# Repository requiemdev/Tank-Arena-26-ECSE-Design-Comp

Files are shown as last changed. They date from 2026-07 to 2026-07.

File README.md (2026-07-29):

# Tank Arena — Laser Tank Duels

**Winner of the Part III Engineering Excellence Award at the 2026 University of Auckland ECSE Design Competition.**



Tank Arena is a two-player tank duel game that combines custom 3D-printed tanks, ESP32 embedded firmware, electrical design, and a browser-based control experience. Players drive and fire from their phones while an edge server coordinates the match, validates gameplay, reports hits, and records completed results.

<br clear="both">

## Project Key Points



This is a complete hardware–software product rather than a standalone robot or web demo:

- Two custom RC tanks communicate with the server over Wi-Fi and WebSockets.
- Players use responsive browser controllers instead of dedicated transmitters.
- The server owns the authoritative match state, including readiness, countdowns, movement, firing, health, scoring, and win conditions.
- Hit events from the tanks are sent back through the same WebSocket connection, keeping the game state synchronized.
- Completed games are queued locally in SQLite and synchronized to Supabase when connectivity is available.
- Spectator and leaderboard views make the system usable beyond the players themselves.

<br clear="both">

## System overview



1. Players open `/controller` on their phones, select a tank, and ready up.
2. Each ESP32 tank connects to `/connect?type=tank&player=p1|p2`.
3. The TypeScript/Fastify server broadcasts state and forwards normalized movement and firing commands to the correct tank.
4. The tanks detect laser hits and report them to the server, which applies damage and updates the score.
5. A decisive match ends when one tank reaches zero health. The result is persisted locally and can appear on the leaderboard.

The game lifecycle is explicitly modelled as `LOBBY → COUNTDOWN → ACTIVE → ENDED`, which keeps connection loss, invalid actions, and match completion predictable.

<br clear="both">

## Engineering highlights

- **Embedded systems:** ESP32 firmware for Wi-Fi, WebSocket communication, watchdog/reconnect behaviour, String parsing to encode/decode messages from server, interrupt handling for hit sensing, PWM outputs (for motor control and IR emitter firing).
- **Real-time networking:** Persistent WebSocket connections for low-latency control and event delivery.
- **Authoritative game logic:** Server-side validation prevents the browser from directly deciding hits, health, scores, or winners.
- **Resilient operation:** Connection lifecycle handling, safe match termination, local SQLite queueing, and deferred cloud synchronization support unreliable competition-day networks.
- **Player-focused UX:** The controller exposes connection status, readiness, joystick movement, firing cooldown, health, score, and hit feedback at a glance.
- **End-to-end integration:** Mechanical fabrication, circuit simulation, firmware, backend services, and user interface are designed as one system.

## Hardware and design files

- [3D_Print](./3D_Print) — STL files for the tank body and supporting parts. The rigid components were printed in PLA; the wheel tracks were printed in flexible TPU.
- [Firmware](./Firmware) — ESP32 firmware for tank control, sensing, firing, and communication with the game server.
- [LTspice](./LTspice) — circuit simulations and supporting electrical-design work.
- [Altium](./dc_p3_t11) — PCB design for circuit.

## Software stack

| Area | Technologies |
| --- | --- |
| Embedded control | ESP32, C++, Arduino/PlatformIO |
| Game server | TypeScript, Node.js, Fastify, WebSockets |
| Player interface | HTML, CSS, JavaScript, responsive mobile UI |
| Persistence | SQLite offline queue, Supabase leaderboard |
| Mechanical design | 3D printing with PLA and TPU |
| Electrical design | Altium, LTspice |

## Running the software locally

```bash
npm install
npm run dev
```

Once the server is running, open the controller at:

```text
http://localhost:8080/controller
```

For a tank or robot client on the same network, replace the router/server address and choose `p1` or `p2`:

```bash
EDGE_WS_URL=ws://<router-ip>:8080/connect PLAYER=p1 npm run robot
```

The server address must be reachable by both phones and ESP32 boards. The exact firmware build and flashing instructions are documented with the source in [Firmware](./Firmware).

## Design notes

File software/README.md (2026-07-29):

# ECSE Edge Tank Server

MVP for a local-router tank game:

- Browser controller at `http://<router-ip>:8080/controller`
- Live spectator display at `http://<router-ip>:8080/spectator`
- WebSocket edge route at `ws://<router-ip>:8080/connect`
- Robot client connects as a tank and receives normalized `{ throttle, steering, fire, left, right, seq, ts }` commands
- Match results queue locally in SQLite and sync to Supabase when internet is available

## Run on the Local Router

```sh
npm install
cp .env.example .env
npm run dev
```

Open `http://<router-ip>:8080/controller` from each player's phone or laptop on the same Wi-Fi.
Open `http://<router-ip>:8080/spectator` on the shared display for the live VS view.

On Windows PowerShell, create the local `.env` file with:

```powershell
Copy-Item .env.example .env
```

If `npm install` prints an `allow-scripts` warning for `better-sqlite3` or `esbuild`, approve those install scripts and rebuild before starting the server:

```sh
npm approve-scripts --allow-scripts-pending
npm rebuild
npm run dev
```

The dev server should keep running and print a `Server listening at http://0.0.0.0:8080` log. If it exits immediately with `node: .env: not found`, create `.env` from `.env.example` first.

## Supabase Setup

Create the leaderboard table before enabling cloud sync:

1. Open Supabase dashboard.
2. Go to SQL Editor.
3. Run `supabase/schema.sql`.

Set `SUPABASE_URL` and `SUPABASE_SERVICE_ROLE_KEY` in `.env`. Match results stay in local SQLite until Supabase sync succeeds.
Only matches with a winner are added to the leaderboard. The leaderboard ranks those matches by shortest game duration; legacy rows without a recorded duration are retained but not shown.

## Connect a Robot

On the robot or a process that can reach the robot hardware API:

```sh
EDGE_WS_URL=ws://<router-ip>:8080/connect PLAYER=p1 npm run robot
```

By default the robot client logs commands for bench testing. To forward commands to hardware, expose an HTTP endpoint on the robot and set:

```sh
ROBOT_COMMAND_URL=http://127.0.0.1:5000/drive EDGE_WS_URL=ws://<router-ip>:8080/connect PLAYER=p1 npm run robot
```

The hardware endpoint receives JSON like:

```json
{
  "throttle": 0.8,
  "steering": -0.4,
  "fire": false,
  "left": true,
  "right": false,
  "seq": 12,
  "ts": 1800000000000
}
```

When the robot detects that its own tank was hit, send the event through the same tank WebSocket connection:

```json
{
  "type": "hit",
  "direction": "front"
}
```

The server uses the connected tank's player slot to reduce that tank's health and update the opposing player's score. Direction is logged for debugging only, so every direction counts as a regular hit.

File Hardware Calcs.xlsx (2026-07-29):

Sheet: Sheet1
Emitter |  |  | Receiver |  | Electrical Parameters
Radiant Intensity | 0.063 |  | Min Sensor Distance | 0.15 | Emitter Frequency (Hz) | 38000
 |  |  | Max Sensor Distance | 0.3
 |  |  | Responsivity | 0.6
Relative Emission | 90% |  | Relative Sensitivity | 93%
Intensity at 850nm (W/sr) | 0.0567 |  | Detection Area | 1e-06
 | Min | Max
Detection sr | 1.111111111e-05 | 4.444444444e-05
Detection Intensity (W) | 6.3e-07 | 2.52e-06
Detection Current (A) | 3.5154e-07 | 1.40616e-06

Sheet: 2_emitter calc
Emitter |  |  | Receiver |  | Electrical Parameters
Radiant Intensity | 0.063 |  | Min Sensor Distance | 0.15 | Emitter Frequency (Hz) | 38000
 |  |  | Max Sensor Distance | 0.3 | Duty Cycle | 0.5
 |  |  | Responsivity | 0.6
Relative Emission | 90% |  | Relative Sensitivity | 93%
Intensity at 850nm (W/sr) | 0.0567 |  | Detection Area | 1e-06
 | Min | Max
Detection sr | 1.111111111e-05 | 4.444444444e-05
Detection Intensity (W) | 6.3e-07 | 2.52e-06
Detection Current (A) | 3.5154e-07 | 1.40616e-06

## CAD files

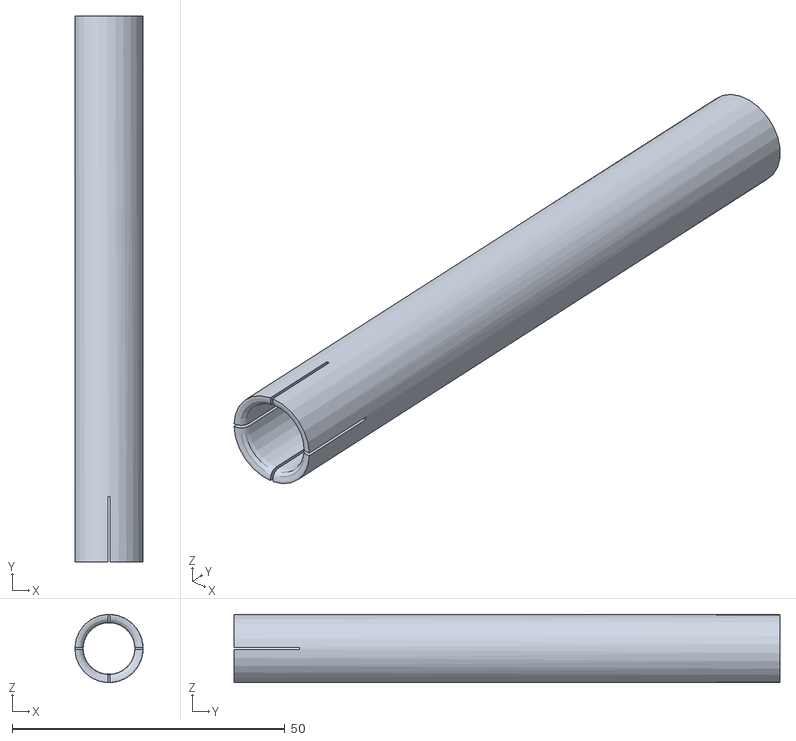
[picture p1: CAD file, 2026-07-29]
3D_Print/Outputs/Turret_extend.stl
12.5 x 100.0 x 12.5

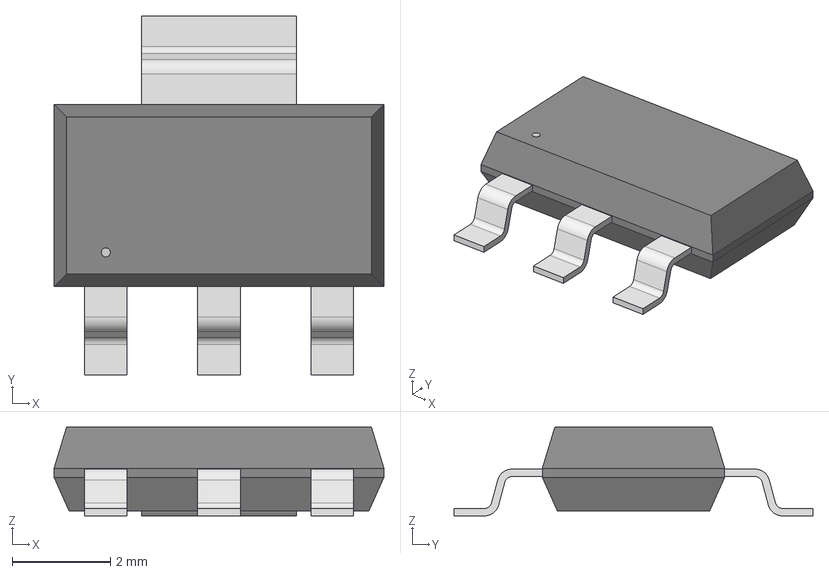
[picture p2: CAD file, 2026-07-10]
dc_p3_t11/LD1117S33CTR/Altium/LD1117S33CTR/SOT-223_STM.step
6.71 x 7.29 x 1.81 mm

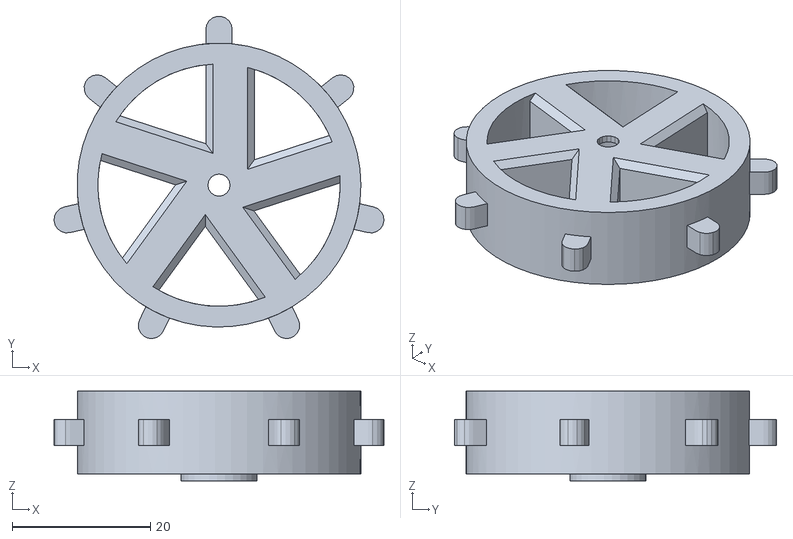
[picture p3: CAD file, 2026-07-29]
3D_Print/Outputs/wheel_front.stl
47.7 x 46.5 x 13.0

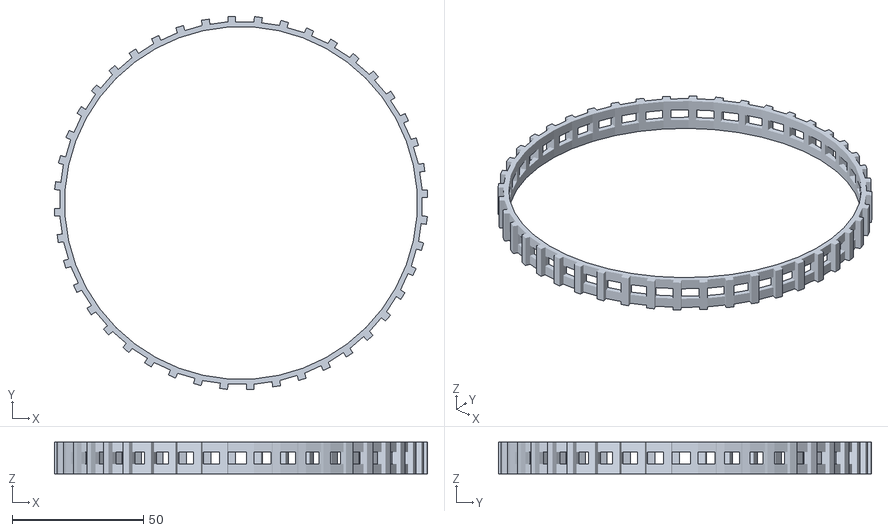
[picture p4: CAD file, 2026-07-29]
3D_Print/Outputs/good_track.stl
142.0 x 142.0 x 12.0

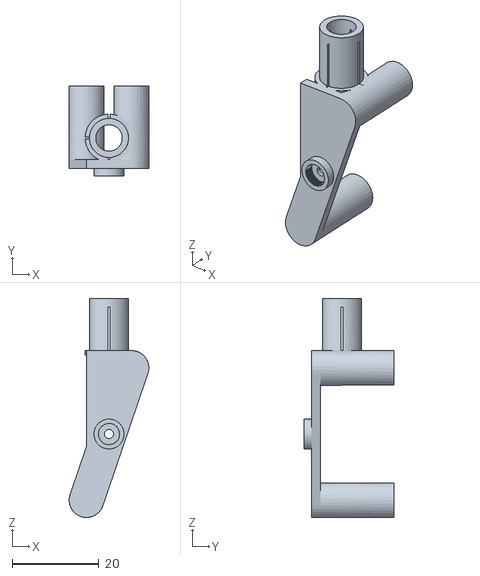
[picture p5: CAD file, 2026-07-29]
3D_Print/Outputs/turret_mount.stl
18.4 x 20.8 x 50.5

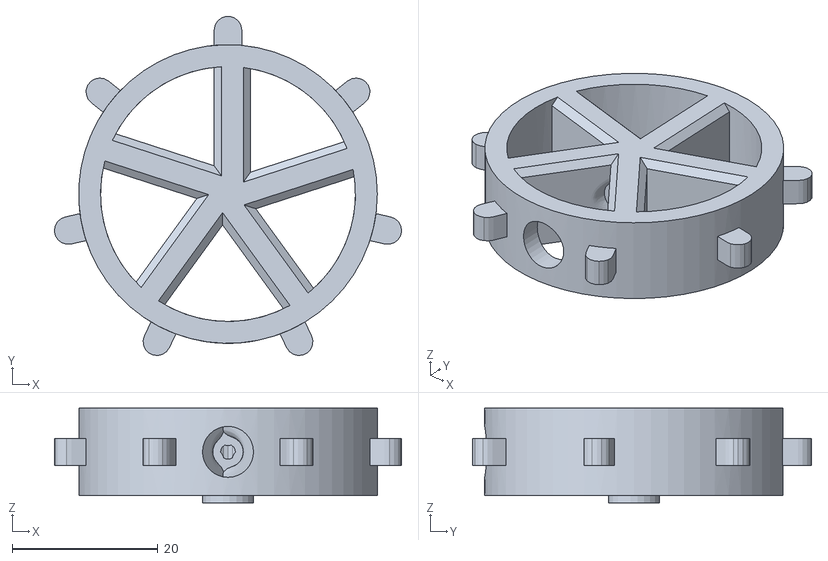
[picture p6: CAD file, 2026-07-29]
3D_Print/Outputs/wheel_back.stl
47.7 x 46.5 x 13.0

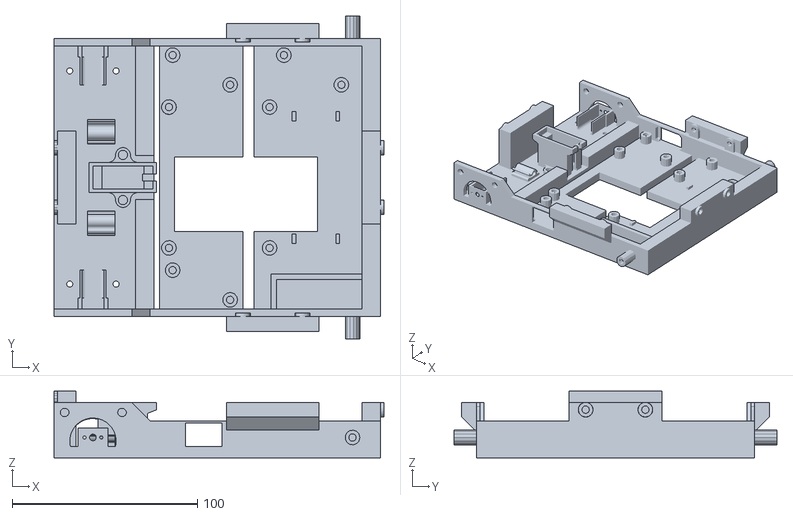
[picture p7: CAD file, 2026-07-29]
3D_Print/Outputs/tank_body.stl
178.0 x 174.0 x 36.0

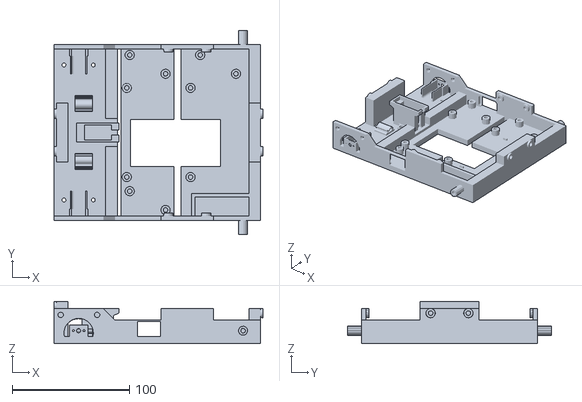
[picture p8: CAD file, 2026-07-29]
3D_Print/Outputs/MEOWtank_bodyBIBIPRINTTHISONEFORREALNOCAP.stl
178.0 x 174.0 x 36.0

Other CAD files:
dc_p3_t11/LD1117S33CTR/SOT-223_STM.stl
3D_Print/Outputs/tank_bodyNEWFRPLZPRINTTHISONEMEOWWWWW.stl
3D_Print/Turret_extend.ipt
3D_Print/battery_case.ipt
3D_Print/battery_protection.ipt
3D_Print/buck_converter.ipt
3D_Print/deform_track.ipt
3D_Print/good_track.ipt
3D_Print/tank_body.ipt
3D_Print/track_bigger.ipt
3D_Print/turret_mount.ipt
3D_Print/wheel_big.ipt
3D_Print/wheel_small.ipt

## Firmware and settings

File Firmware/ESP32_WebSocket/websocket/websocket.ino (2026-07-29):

#include <Arduino.h>
#include <WiFi.h>
#include <WebSocketsClient.h>

// Install "WebSockets" by Markus Sattler from the Arduino Library Manager.

const char *WIFI_SSID = "TankRouter";
const char *WIFI_PASSWORD = "WeLoveTanksPewPew";

const char *SERVER_HOST = "192.168.1.67";
const uint16_t SERVER_PORT = 8080;
const char *PLAYER_SLOT = "p1"; // Use "p1" or "p2".
const char *ROBOT_NAME = "esp32-tank";

WebSocketsClient webSocket;

void connectWiFi();
void configureWebSocket();
void handleWebSocketEvent(WStype_t type, uint8_t *payload, size_t length);
void printPayload(uint8_t *payload, size_t length);

void setup() {
  Serial.begin(115200);
  delay(500);

  Serial.println();
  Serial.println("ESP32 tank listener starting");

  connectWiFi();
  configureWebSocket();
}

void loop() {
  webSocket.loop();

  if (WiFi.status() != WL_CONNECTED) {
    Serial.println("[wifi] disconnected; reconnecting");
    connectWiFi();
  }
}

void connectWiFi() {
  WiFi.mode(WIFI_STA);
  WiFi.begin(WIFI_SSID, WIFI_PASSWORD);

  Serial.print("[wifi] connecting");
  while (WiFi.status() != WL_CONNECTED) {
    delay(500);
    Serial.print(".");
  }

  Serial.println();
  Serial.print("[wifi] connected: ");
  Serial.println(WiFi.localIP());
}

void configureWebSocket() {
  String path = "/connect?type=tank&player=";
  path += PLAYER_SLOT;
  path += "&username=";
  path += ROBOT_NAME;

  Serial.print("[ws] connecting to ws://");
  Serial.print(SERVER_HOST);
  Serial.print(":");
  Serial.print(SERVER_PORT);
  Serial.println(path);

  webSocket.begin(SERVER_HOST, SERVER_PORT, path);
  webSocket.onEvent(handleWebSocketEvent);
  webSocket.setReconnectInterval(1000);
  webSocket.enableHeartbeat(15000, 3000, 2);
}

void handleWebSocketEvent(WStype_t type, uint8_t *payload, size_t length) {
  switch (type) {
    case WStype_DISCONNECTED:
      Serial.println("[ws] disconnected");
      break;

    case WStype_CONNECTED:
      Serial.println("[ws] connected");
      webSocket.sendTXT("{\"type\":\"tank-listener-online\"}");
      break;

    case WStype_TEXT:
      Serial.print("[ws] message ");
      Serial.print(length);
      Serial.print(" bytes: ");
      printPayload(payload, length);
      Serial.println();
      break;

    case WStype_BIN:
      Serial.print("[ws] binary message ");
      Serial.print(length);
      Serial.println(" bytes");
      break;

    case WStype_ERROR:
      Serial.print("[ws] error: ");
      printPayload(payload, length);
      Serial.println();
      break;

    case WStype_PING:
      Serial.println("[ws] ping");
      break;

    case WStype_PONG:
      Serial.println("[ws] pong");
      break;

    default:
      break;
  }
}

void printPayload(uint8_t *payload, size_t length) {
  for (size_t i = 0; i < length; i += 1) {
    Serial.write(payload[i]);
  }
}

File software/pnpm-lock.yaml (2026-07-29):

lockfileVersion: '9.0'

settings:
  autoInstallPeers: true
  excludeLinksFromLockfile: false

importers:

  .:
    dependencies:
      '@supabase/supabase-js':
        specifier: ^2.45.4
        version: 2.110.5
      better-sqlite3:
        specifier: ^12.10.0
        version: 12.11.1
      fastify:
        specifier: ^4.28.1
        version: 4.29.1
      tsx:
        specifier: ^4.19.1
        version: 4.23.1
      ws:
        specifier: ^8.18.0
        version: 8.21.1
    devDependencies:
      '@types/better-sqlite3':
        specifier: ^7.6.11
        version: 7.6.13
      '@types/node':
        specifier: ^22.5.4
        version: 22.20.1
      '@types/ws':
        specifier: ^8.5.12
        version: 8.18.1
      typescript:
        specifier: ^5.6.2
        version: 5.9.3

packages:

  '@esbuild/aix-ppc64@0.28.1':
    resolution: {integrity: sha512-Svl7tq8k/08+p6CXPpRjQ1fKX+1odH/BQbb48fV6fj3CWHhsoIOoY87w1oHXm0qEpkIK3ZfVgp0hed3XBXzXMQ==}
    engines: {node: '>=18'}
    cpu: [ppc64]
    os: [aix]

  '@esbuild/android-arm64@0.28.1':
    resolution: {integrity: sha512-34EGEbCIAgosYz6goLcopX6Mo7NyGv9tfwEM2/7Ce2VcVRk568iSvniGWcUXIy7wEDR1wzolcxcriFVrWYcwBg==}
    engines: {node: '>=18'}
    cpu: [arm64]
    os: [android]

  '@esbuild/android-arm@0.28.1':
    resolution: {integrity: sha512-0k2F129Xdio1TdJfzJ8sy1Q47vUD2NnwdhiAf7drUN1EBTfPf4hsFCtmMgu/6m8JSzsBrlmVjudMBQqOfG8usQ==}
    engines: {node: '>=18'}
    cpu: [arm]
    os: [android]

  '@esbuild/android-x64@0.28.1':
    resolution: {integrity: sha512-dbwY7ltSMDWsRatcRpCnES4F+im88OCUgGZjy52shC7GqHRE/cYlxNbB4Z4UpJswpcc4Qxd2oE/ufM0p61IKng==}
    engines: {node: '>=18'}
    cpu: [x64]
    os: [android]

  '@esbuild/darwin-arm64@0.28.1':
    resolution: {integrity: sha512-TZbWkQY7kvTAXbXUT7uVACR5cMHsDiSz9z7ZKAX/RTq/WJEk3QyRr0wZpNhBDX+/0CtdqUIJlOiodQcta6tY3Q==}
    engines: {node: '>=18'}
    cpu: [arm64]
    os: [darwin]

  '@esbuild/darwin-x64@0.28.1':
    resolution: {integrity: sha512-zfdzgK9ACBNZLI/CyHTOx81SyNbM6YXn7rxSgX97VjyiPl9W1i4Ka4fgKECEoFCKGpvBj5qArWIGgQjOwkgskQ==}
    engines: {node: '>=18'}
    cpu: [x64]
    os: [darwin]

  '@esbuild/freebsd-arm64@0.28.1':
    resolution: {integrity: sha512-wG2EA8ENdEI0qhkSZMjfqrdY+ziCYCPMmtZjjIwOmXFjmyzEHn+UUxk5of+SYsjtfs3VpnlC7QLzSI5hY/rOAw==}
    engines: {node: '>=18'}
    cpu: [arm64]
    os: [freebsd]

  '@esbuild/freebsd-x64@0.28.1':
    resolution: {integrity: sha512-i7dZ9vQgnvSCzi/rYCXNgtF/U+eKZNJBzu3eTQbRgHnM7tNSizLOkRFAl3qzVc/Op/u5YkHHa4pf/3DOYHthLQ==}
    engines: {node: '>=18'}
    cpu: [x64]
    os: [freebsd]

  '@esbuild/linux-arm64@0.28.1':
    resolution: {integrity: sha512-yHs+0uc8+nvEAfAfxrWQKK5peSNzBc4PegcMO0EJ2hT71uA7vB8Ihg2e77R2P7SG5uYjPbHlLLmve4LLLRCf0g==}
    engines: {node: '>=18'}
    cpu: [arm64]
    os: [linux]

  '@esbuild/linux-arm@0.28.1':
    resolution: {integrity: sha512-qVXBOHQS+d5Y722GwJzJUtOLlX7km3CraOaGormF1pDtPd2C/l1SHRPgjLunLGe51Sh5YYWKMFDyV4SxgMQYTQ==}
    engines: {node: '>=18'}
    cpu: [arm]
    os: [linux]

  '@esbuild/linux-ia32@0.28.1':
    resolution: {integrity: sha512-d1z4ZuP0ajrfz/FhGT4vv278rX8KnPPJx8i5+AtK7TYbx9Le9F1hyzurZpkEyjkGa9dUGhQow4C1NmeGvqxN2w==}
    engines: {node: '>=18'}
    cpu: [ia32]
    os: [linux]

  '@esbuild/linux-loong64@0.28.1':
    resolution: {integrity: sha512-M5sRjUVZrkm1OAPR3dlOYzNmN+loZKGVi1VUQGrwuqLcbR6qeAz+famMhjASeH3YVKvZz+zT1jlh/keC3Rj/lg==}
    engines: {node: '>=18'}
    cpu: [loong64]
    os: [linux]

  '@esbuild/linux-mips64el@0.28.1':
    resolution: {integrity: sha512-mRObBZeHh2OxcBFPWE/FjylkRgZdYuiTR3vaTozquCGOH14iP9oN4x4Ge81CoIDYQrXmIxpFumJBu5MtZpnQJQ==}
    engines: {node: '>=18'}
    cpu: [mips64el]
    os: [linux]

  '@esbuild/linux-ppc64@0.28.1':
    resolution: {integrity: sha512-slScBsMAb3GFDcdrCgLwZtPYRoH2H/youv10QiZyRjmsP48fznoveWytSgCI/R0ZcUgpc0ZhIUEx6LHts8yrfQ==}
    engines: {node: '>=18'}
    cpu: [ppc64]
    os: [linux]

  '@esbuild/linux-riscv64@0.28.1':
    resolution: {integrity: sha512-kw0owk1o0GFETUJyW0jc0G4Yzs0BHZn0JDZ8JRT088vjJYX777BAs1fDGxAC+q831qOs2DTC96mNsG2opdfyyQ==}
    engines: {node: '>=18'}
    cpu: [riscv64]
    os: [linux]

  '@esbuild/linux-s390x@0.28.1':
    resolution: {integrity: sha512-/lAIjX8aYFRByhh6L5rYtPEDRqa9de/4V/juOXcta5frjvzXO4/sqEtyytse0g3zZFuWu5cDN0MkLz2qRDD2Ag==}
    engines: {node: '>=18'}
    cpu: [s390x]
    os: [linux]

  '@esbuild/linux-x64@0.28.1':
    resolution: {integrity: sha512-u/anNYF2mmVOEDwLtnQ1wOr3EZ9sTNGLWrsYGYwHWzGA3Si84IOkHXlbWTD1NB+9/1lcnweYKO54uhxZydNzfA==}
    engines: {node: '>=18'}
    cpu: [x64]
    os: [linux]

  '@esbuild/netbsd-arm64@0.28.1':
    resolution: {integrity: sha512-oks0DYbLwWMmaakTsCb+zL4E+aHRVLom9IJZOAthMQEPiQmydXHkziYEsGYRx0uNV/IjEKGAV941JzH02pflqw==}
    engines: {node: '>=18'}
    cpu: [arm64]
    os: [netbsd]

  '@esbuild/netbsd-x64@0.28.1':
    resolution: {integrity: sha512-aeL6lAnN89Hz43Mlh1G8ARasbuoYvSITDEx0tHh5b7jJnHcssqgjy9Yx430GDpmCa6OyrKoS0aNRjKundRizGg==}
    engines: {node: '>=18'}
    cpu: [x64]
    os: [netbsd]
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

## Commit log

2026-06-12 Created pcb file
    [dc_p3_t11.PrjPcb, dc_p3_t11_PCB.PcbDoc, dc_p3_t11_Sch.SchDoc]
2026-06-12 Updated pcb
    [dc_p3_t11_Sch.SchDoc]
2026-06-12 Added simulations and modified circuit
    [dc_p3_t11_Sch.SchDoc]
2026-06-12 updated project files
    [dc_p3_t11.PrjPcb, dc_p3_t11_Sch.SchDoc]
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2026-06-13 Adjusted band pass filter stage and added envelope detector
2026-06-13 Added comparator
    [lm393.dsn]
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2026-06-14 Added excel spreadsheet for value calculations.
    [Hardware Calcs.xlsx]
2026-06-14 Updated circuit
    [Hardware Calcs.xlsx]
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2026-06-14 Updated altium pcb
    [dc_p3_t11_Sch.SchDoc]
2026-06-14 Cleaned up altium pcb
    [dc_p3_t11_Sch.SchDoc]
2026-06-14 Changed photodiode circuit so source has same duty cycle as input to sensor circuit.
2026-06-15 updated laser model to use diode instead of current source
2026-06-15 Replaced npn with nmos for led switching
2026-06-16 Updated pcb doc
    [dc_p3_t11_PCB.PcbDoc, dc_p3_t11_Sch.SchDoc, sensor.SchDoc]
2026-06-16 further pcb and schematic progress
    [comparator.SchDoc, dc_p3_t11_PCB.PcbDoc, dc_p3_t11_Sch.SchDoc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]
2026-06-16 Added extra schematic files to project.
    [dc_p3_t11.PrjPcb, dc_p3_t11_Sch.SchDoc]
2026-06-16 Added circuitry for motor driver
    [dc_p3_t11_Sch.SchDoc]
2026-06-16 Added comments to main schematic.
    [dc_p3_t11_Sch.SchDoc]
2026-06-16 Saved project file correctly.
    [dc_p3_t11_Sch.SchDoc]
2026-06-17 draft sensor circuit
    [comparator.SchDoc, dc_p3_t11_PCB.PcbDoc, dc_p3_t11_Sch.SchDoc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]
2026-06-17 pcb update
    [dc_p3_t11_PCB.PcbDoc]
2026-06-17 circuit bugfixes
    [dc_p3_t11_PCB.PcbDoc]
2026-06-17 missing save changes
    [dc_p3_t11.PrjPcb, sensor.SchDoc]
2026-06-17 Added decoupling circuit in LTSpice schematic after comparator.
2026-06-18 Made a sensor circuit in PCB.
    [dc_p3_t11_PCB.PcbDoc, sensor.SchDoc]
2026-06-18 Redrew PCB to ensure components have correct pad layer positions.
    [dc_p3_t11_PCB.PcbDoc]
2026-06-18 optimised sensor pcb layout
    [dc_p3_t11_PCB.PcbDoc]
2026-06-18 minor adjustments to design
    [dc_p3_t11_PCB.PcbDoc]
2026-06-18 further adjustments to sensor pcb
    [dc_p3_t11_PCB.PcbDoc]
2026-06-19 Assembled one of the photodiode circuits US1
    [dc_p3_t11_PCB.PcbDoc, dc_p3_t11_Sch.SchDoc]
2026-06-19 Redrew polygons on photodiode pcb circuit.
    [dc_p3_t11_PCB.PcbDoc]
2026-06-20 Marked "Safe Pins to Use" on ESP32.
    [dc_p3_t11_PCB.PcbDoc, dc_p3_t11_Sch.SchDoc]
2026-06-20 Assigned some pins to motor controller.
    [comparator.SchDoc, dc_p3_t11_Sch.SchDoc]
2026-06-20 MCU pin setting.
    [dc_p3_t11_Sch.SchDoc]
2026-06-20 Updated PCB routing
    [dc_p3_t11.PrjPcb]
2026-06-20 Added comments as TO-DO list on PCB.
    [dc_p3_t11_Sch.SchDoc]
2026-06-20 Various updates to schematic
    [LD1117S33CTR.PcbLib, LD1117S33CTR.SchLib, SOT-223_STM.step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]
2026-06-20 Updated pcb settings
    [dc_p3_t11_PCB.PcbDoc]
2026-06-20 small adjustment to pcb
    [dc_p3_t11.PrjPcb]
2026-06-21 modified constraints to pcb
    [dc_p3_t11_PCB.PcbDoc]
2026-06-21 Updated PCB document with changes from schematic
    [dc_p3_t11_PCB.PcbDoc, dc_p3_t11_Sch.SchDoc]
2026-06-21 Made all photodiode sensor circuits into Vickey's design.
    [dc_p3_t11_PCB.PcbDoc, dc_p3_t11_Sch.SchDoc]
2026-06-21 Made comparator circuit draft (PCB).
    [dc_p3_t11.PrjPcb, dc_p3_t11_Sch.SchDoc, sensor.SchDoc]
2026-06-27 Adjusted schematic
    [dc_p3_t11_Sch.SchDoc]
2026-06-28 Laid out comparator components on schematic
    [comparator.SchDoc, dc_p3_t11_Sch.SchDoc]
2026-06-29 Added wires and polygons into comparator circuit routing
2026-06-29 Added wires and planes to 'complete' top half of PCB
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2026-06-29 Added motor controller circuit to PCB.
    [dc_p3_t11_Sch.SchDoc]
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2026-06-30 updated motor circuit
    [comparator.SchDoc, dc_p3_t11.PrjPcb, dc_p3_t11_Sch.SchDoc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]
2026-06-30 Completed board and fixed design rule checks
    [comparator.SchDoc, dc_p3_t11.PrjPcb, dc_p3_t11_PCB.PcbDoc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]
2026-06-30 Added moutning holes to main board
    [dc_p3_t11_PCB.PcbDoc]
2026-06-30 Added top layer ground pour to main board
2026-06-30 Made some extra pads and adjustments to LED circuit.
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2026-07-01 Added buzzer circuit
    [dc_p3_t11_Sch.SchDoc]
2026-07-01 Added ground pads for test points
    [dc_p3_t11_Sch.SchDoc]
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2026-07-08 Added test code for digital, PWM and ADC functionality.
2026-07-08 Added test code for project 2 and reading ADC pin instead of using GPIO number.
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2026-07-12 added button debouncing and Refactored sensor hit code (interrupts) inside sensor file
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2026-07-13 fix bug VICKEY made because he tried to declare a func instead of calling it
    [main.cpp]
2026-07-14 Squashed commit of the following:
    commit a098910f4efaacccb589a5e0ea1cf3e793ec04c2
    Merge: c20367e 71ffbbe
    Author: Vickey Xia <48378916+La1ing@users.noreply.github.com>
    Date: Tue Jul 14 12:42:58 2026 +1200
    Merge branch 'websocket_combine' into Firmware
    commit c20367e90bca0464e5c8f9d5bf4e156c12f6b52c
    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
    [sensor.SchDoc]
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2026-07-14 Added LED on a PWM channel and separated PWM channels to run on separate timers.
2026-07-14 Changed resolution of LED to make it work and made main code fully connected to test define.
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2026-07-15 Fixed command reading code and added debug print statements controlled by define.
    [command.cpp]
2026-07-15 Updated with changes made today
    Changed 15p capacitor to 22p, made tank LED into solid light.
2026-07-16 Various changes involving websocket connections.
    Made timer which stops all tank operations when no command has been received for 1s and message is now sent to server when sensor is hit.
    [Hardware Calcs.xlsx]
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2026-07-16 Made some ISR fixes.
    [main.cpp, tank_timers.cpp, websocket.cpp]
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2026-07-20 Sensors now check pin state to prevent false interrupt triggers.
    [sensors.cpp, sensors.h]
2026-07-22 Fixed memory leak in command reading.
    [command.cpp]
2026-07-27 Added 3d models
    [MEOWtank_bodyBIBIPRINTTHISONEFORREALNOCAP.stl, Turret_extend.ipt, Turret_extend.stl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]
